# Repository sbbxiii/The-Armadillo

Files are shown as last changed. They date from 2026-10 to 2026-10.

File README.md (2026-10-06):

# 🛡️ The Armadillo: Custom ATmega328P + TMC2209 Stepper Motor Controller PCB








---

## 1. Executive Summary

**The Armadillo** is an open-source, Arduino-compatible motion control PCB designed from first principles in **KiCad 10.0.1**. It pairs the reliable **Microchip ATmega328P** 8-bit AVR microcontroller with the high-performance **Trinamic TMC2209-LA** silent bipolar stepper motor driver on a rugged $60.0\text{ mm} \times 60.0\text{ mm}$ 2-layer FR-4 board.

Featuring an onboard **WCH CH340K** USB-to-UART converter with automated DTR auto-reset, The Armadillo provides seamless plug-and-play programming directly through the Arduino IDE, PlatformIO, or AVR-GCC toolchains. Key features include silent stepper motion via **StealthChop2™**, sensorless homing via **StallGuard4™**, dynamic runtime current tuning over a single-wire **PD_UART** interface, and hardware RC-filtered sensor inputs.

---

## 2. 3D Raytraced Visualizations

<p align="center">
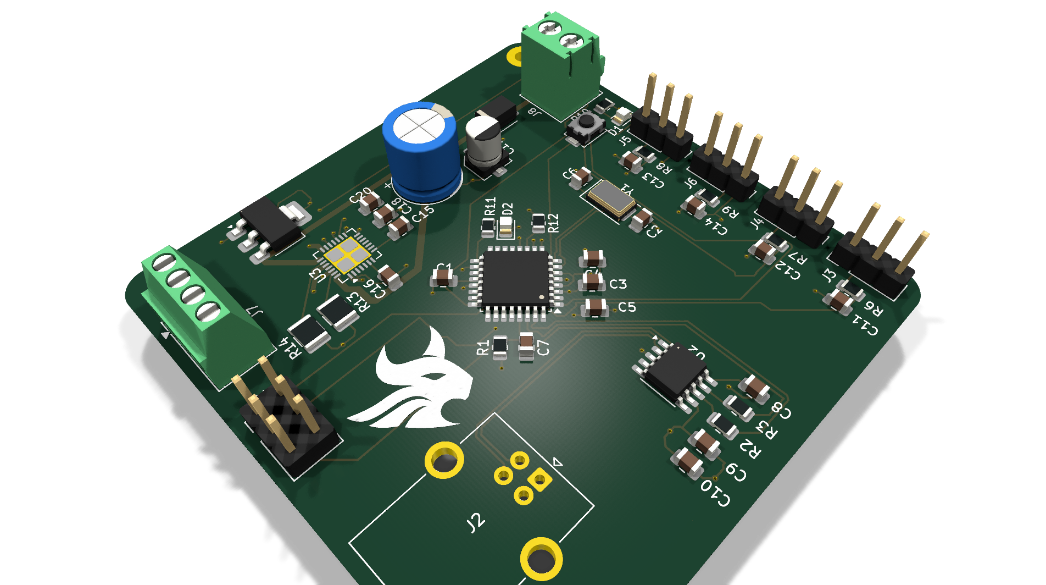
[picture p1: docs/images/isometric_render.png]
The Armadillo 3D Perspective Raytrace
  <br>
  <em>Figure 1: Raytraced 3D perspective view of The Armadillo motor controller board showing the ATmega328P core, TMC2209 driver, and screw terminal I/O.</em>
</p>

| Top View (Silicon, Connectors & SMT Layout) | Bottom View (Solid Ground Return & Driver Thermal Vias) |
| :---: | :---: |
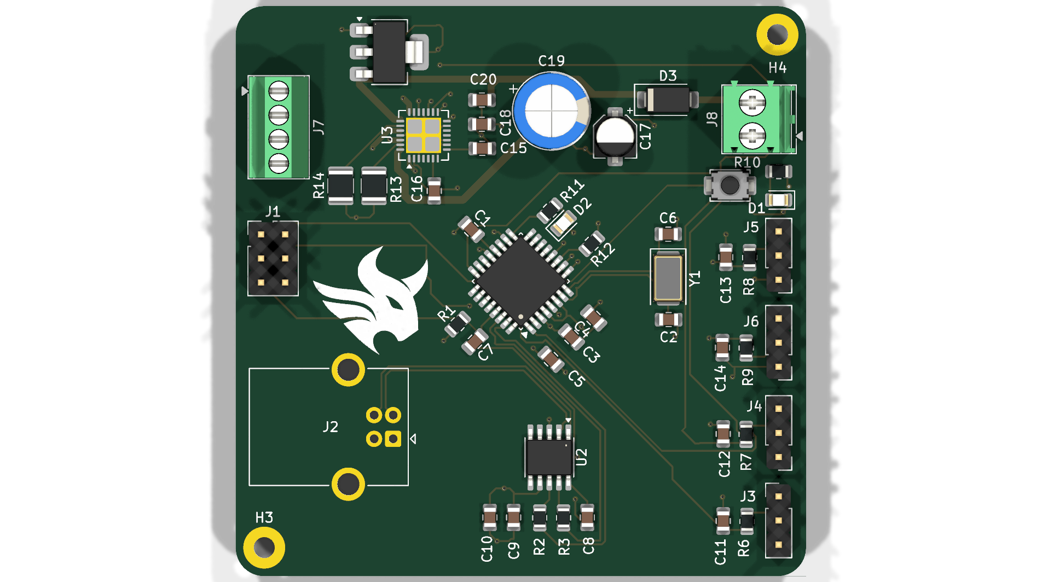
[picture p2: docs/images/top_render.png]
Top View
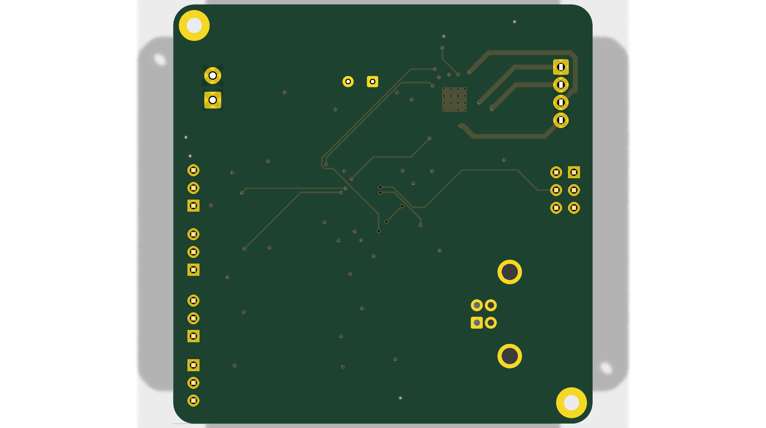
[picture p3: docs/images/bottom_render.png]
Bottom View
|  |  |

---

## 3. Circuit Architecture & Block Diagram

```mermaid
flowchart TD
    subgraph Power_Subsystem ["Power Distribution Network (PDN)"]
        VIN["Motor Power (4.75V - 29V)<br/>Terminal Block J8"] --> BulkCap["Bulk Decoupling<br/>100µF Radial + 2x 100nF"]
        BulkCap --> VMOT["VMOT Supply Rail"]
        VMOT --> LDO["NCP1117-5.0 LDO<br/>(Steps to +5V Logic)"]
        USB["USB Type-B Port (J2)"] --> Schottky["SS14 Schottky Diode (D3)"]
        Schottky --> VCC5["+5V System VCC Rail"]
        LDO --> VCC5
    end

    subgraph MCU_Subsystem ["Microcontroller & Communications"]
        VCC5 --> MCU["ATmega328P-A (TQFP-32)<br/>16.000 MHz Clock"]
        CH340["CH340K USB-UART (U2)"] <-->|"UART RX/TX + DTR Reset"| MCU
        ICSP["6-Pin AVR ISP Header (J1)"] <-->|"SPI MOSI/MISO/SCK/RST"| MCU
        MCU --> LEDS["Power & Diagnostic LEDs<br/>(D1, D2)"]
    end

    subgraph Motion_Subsystem ["Silent Motion Control"]
        VMOT --> TMC["Trinamic TMC2209-LA (U3)<br/>Silent Stepper Driver"]
        VCC5 --> TMC
        MCU -->|"M1_STEP / M1_DIR / EN"| TMC
        MCU <-->|"PD_UART (Single-Wire)"| TMC
        TMC --> SenseRes["Dual 0.11Ω 1210 Sense Resistors<br/>(R13, R14)"]
        TMC --> MotorOut["4-Phase Stepper Terminal (J7)<br/>(A1, A2, B1, B2)"]
    end

    subgraph IO_Subsystem ["Filtered Sensor Inputs"]
        Sensors["Endstops / Sensors (J3 - J6)"] --> RCFilt["RC Low-Pass Filters<br/>(1.5kΩ + 100nF)"]
        RCFilt --> MCU
    end
```

---

## 4. Hardware Specifications & Feature Matrix

### Electrical & Mechanical Metrics
| Specification | Parameter Value | Engineering Notes |
| :--- | :--- | :--- |
| **Board Footprint** | $60.00\text{ mm} \times 60.00\text{ mm}$ | Compact square profile with 3.0 mm radius rounded corners |
| **Mounting Pattern** | 4× M3 Mounting Holes | Positioned at corners for rigid enclosure mounting |
| **Layer Stackup** | 2-Layer FR-4 (1.6 mm thickness) | Top signal/routing + solid bottom GND return plane |
| **Motor Input Voltage ($V_S$)** | **4.75V to 29.0V DC** | Accepts standard 12V or 24V industrial/3D-printer power supplies |
| **Motor Peak Current** | **2.8A Peak / 2.0A RMS** | Configurable in software via TMC2209 internal registers |
| **Current Sense Resistors** | Dual $0.11\ \Omega \pm 1\%$ (1210 SMT) | High power dissipation footprint for thermal stability |
| **Microstepping Modes** | Up to **1/256** | Native 1/16 with MicroPlyer™ interpolation to 1/256 |
| **Microcontroller** | ATmega328P-A (TQFP-32) | 32 KB Flash, 2 KB SRAM, 1 KB EEPROM @ 16 MHz |
| **USB Interface** | CH340K (SSOP-10) | Built-in clock, requires no external crystal |
| **Design Rule Check (DRC)** | **0 Errors, 0 Unconnected Items** | 100% compliant with standard 2-layer PCB fabrication rules |

---

## 5. Trinamic TMC2209 Key Technologies

1. **StealthChop2™**: Voltage-regulated chopper providing completely silent motor movement at low and medium velocities. Eliminates motor whine.
2. **SpreadCycle™**: Highly dynamic current control chopper mode that delivers high torque and precise microstepping at high step frequencies.
3. **StallGuard4™**: Real-time sensorless load measurement that detects mechanical endstops by monitoring motor back-EMF, eliminating mechanical limit switches.
4. **Single-Wire PD_UART**: Allows the ATmega328P to dynamically tune drive current, chopper thresholds, microstep resolution, and read motor diagnostics via one GPIO pin.

---

## 6. Pinout & Peripheral Mapping

### Microcontroller Pin Mapping
| ATmega328P Pin | Net Name | Hardware Function / Target Peripheral |
| :---: | :--- | :--- |
| **Pin 1 (PD3)** | `M1_STEP` | Step pulse command to TMC2209 Pin 16 |
| **Pin 2 (PD4)** | `M1_DIR` | Direction pulse command to TMC2209 Pin 17 |
| **Pin 9 (PB6)** | `XTAL1` | 16.000 MHz Crystal Oscillator ($Y1$) |
| **Pin 10 (PB7)** | `XTAL2` | 16.000 MHz Crystal Oscillator ($Y1$) |
| **Pin 11 (PD5)** | `EN` | Motor output enable/disable (active low) to TMC2209 Pin 18 |
| **Pin 12 (PD6)** | `PD_UART` | Half-duplex single-wire UART communication with TMC2209 Pin 20 |
| **Pin 13 (PD7)** | `DIAGNOSTIC` | StallGuard / fault flag input from TMC2209 Pin 22 |
| **Pin 15 (PB1)** | `DIGITAL_IN1` | Filtered digital input via header $J5$ (RC filtered) |
| **Pin 16 (PB2)** | `DIGITAL_IN2` | Filtered digital input via header $J6$ (RC filtered) |
| **Pin 17 (PB3)** | `MOSI` | SPI Master Out / In-System Programming ($J1$) |
| **Pin 18 (PB4)** | `MISO` | SPI Master In / In-System Programming ($J1$) |
| **Pin 19 (PB5)** | `SCK` | SPI Clock / In-System Programming ($J1$) |
| **Pin 23 (PC0)** | `ANALOG_IN3` | Filtered analog/digital input via header $J3$ |
| **Pin 24 (PC1)** | `ANALOG_IN4` | Filtered analog/digital input via header $J4$ |
| **Pin 29 (PC6)** | `RESET` | Active-low reset tied to tactile switch $SW1$ and CH340K DTR line |
| **Pin 30 (PD0)** | `RXD` (`UART-`) | Hardware UART receive from CH340K USB bridge |
| **Pin 31 (PD1)** | `TXD` (`UART+`) | Hardware UART transmit to CH340K USB bridge |

### External Connectors
| Connector | Type | Net Connections | Function |
| :--- | :--- | :--- | :--- |
| **J1** | 2×3 2.54mm Header | MOSI, MISO, SCK, RESET, VCC, GND | Standard AVR ICSP programming port |
| **J2** | USB Type-B Female | VBUS, D-, D+, GND | PC programming and USB serial communication |
| **J3** | 1×3 2.54mm Header | VCC, `ANALOG_IN3` (filtered), GND | Sensor / Potentiometer input |
| **J4** | 1×3 2.54mm Header | VCC, `ANALOG_IN4` (filtered), GND | Sensor / Limit switch input |
| **J5** | 1×3 2.54mm Header | VCC, `DIGITAL_IN1` (filtered), GND | Optical / Mechanical Endstop input |
| **J6** | 1×3 2.54mm Header | VCC, `DIGITAL_IN2` (filtered), GND | Optical / Mechanical Endstop input |
| **J7** | 4-Pin 2.54mm Screw Terminal | Motor Coils: `A1`, `A2`, `B1`, `B2` | Stepper motor phase output |
| **J8** | 2-Pin 3.5mm Screw Terminal | `VIN` ($4.75\text{V} - 29\text{V}$), `GND` | Main motor power supply input |

---

## 7. Deliverables & Production Assets

| Asset Category | File Path | Description |
| :--- | :--- | :--- |
| **Schematic Vector PDF** | [`schematic/ATmega_TMC2209_Schematic.pdf`](schematic/ATmega_TMC2209_Schematic.pdf) | High-resolution printable schematic |
| **Schematic Vector SVG** | [`schematic/ATmega_TMC2209_Schematic.svg`](schematic/ATmega_TMC2209_Schematic.svg) | Scalable vector graphic of complete circuit |
| **Bill of Materials** | [`manufacturing/ATmega_TMC2209_BOM.csv`](manufacturing/ATmega_TMC2209_BOM.csv) | Full component list with footprints and quantities |
| **Fabrication Package** | [`manufacturing/ATmega_TMC2209_Gerbers_Rev1.zip`](manufacturing/ATmega_TMC2209_Gerbers_Rev1.zip) | Production gerbers & Excellon drill file |
| **KiCad 10 Project** | [`hardware/`](hardware/) | Native `.kicad_pro`, `.kicad_sch`, and `.kicad_pcb` CAD files |

---

## 8. Author & License

* **Designed & Engineered by:** Osakwe Nmesoma Chukwukadibia ([@sbbxiii](https://github.com/sbbxiii))
* **License:** [MIT License](LICENSE)

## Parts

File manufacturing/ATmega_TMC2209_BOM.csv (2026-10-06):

Refs | Value | Footprint | Qty | DNP
C1 | 100nF | Capacitor_SMD:C_0805_2012Metric | 1
C2 | 22pF | Capacitor_SMD:C_0805_2012Metric | 1
C3 | 100nF | Capacitor_SMD:C_0805_2012Metric | 1
C4 | 100nF | Capacitor_SMD:C_0805_2012Metric | 1
C5 | 100nF | Capacitor_SMD:C_0805_2012Metric | 1
C6 | 22pF | Capacitor_SMD:C_0805_2012Metric | 1
C7 | 100nF | Capacitor_SMD:C_0805_2012Metric | 1
C8 | 100nF | Capacitor_SMD:C_0805_2012Metric | 1
C9 | 100nF | Capacitor_SMD:C_0805_2012Metric | 1
C10 | 100nF | Capacitor_SMD:C_0805_2012Metric | 1
C11 | 100nF | Capacitor_SMD:C_0805_2012Metric | 1
C12 | 100nF | Capacitor_SMD:C_0805_2012Metric | 1
C13 | 100nF | Capacitor_SMD:C_0805_2012Metric | 1
C14 | 100nF | Capacitor_SMD:C_0805_2012Metric | 1
C15 | 100nF | Capacitor_SMD:C_0805_2012Metric | 1
C16 | 100nF | Capacitor_SMD:C_0805_2012Metric | 1
C17 | 4.7uF | Capacitor_SMD:CP_Elec_4x5.3 | 1
C18 | 100nF | Capacitor_SMD:C_0805_2012Metric | 1
C19 | 100uF | Capacitor_THT:CP_Radial_D8.0mm_P3.50mm | 1
C20 | 100nF | Capacitor_SMD:C_0805_2012Metric | 1
D1 | POWER_LED | LED_SMD:LED_0805_2012Metric | 1
D2 | DIAGNOSTIC | LED_SMD:LED_0805_2012Metric | 1
D3 | SS14 | Diode_SMD:D_SMA | 1
J1 | ISP | Connector_PinHeader_2.54mm:PinHeader_2x03_P2.54mm_Vertical | 1
J2 | USB_B | Connector_USB:USB_B_OST_USB-B1HSxx_Horizontal | 1
J3 | J_IN3 | Connector_PinHeader_2.54mm:PinHeader_1x03_P2.54mm_Vertical | 1
J4 | J_IN4 | Connector_PinHeader_2.54mm:PinHeader_1x03_P2.54mm_Vertical | 1
J5 | J_IN1 | Connector_PinHeader_2.54mm:PinHeader_1x03_P2.54mm_Vertical | 1
J6 | J_IN2 | Connector_PinHeader_2.54mm:PinHeader_1x03_P2.54mm_Vertical | 1
J7 | Output_Phases | TerminalBlock_Phoenix:TerminalBlock_Phoenix_MPT-0,5-4-2.54_1x04_P2.54mm_Horizontal | 1
J8 | Power_Input | TerminalBlock_Phoenix:TerminalBlock_Phoenix_PT-1,5-2-3.5-H_1x02_P3.50mm_Horizontal | 1
R1 | 10kΩ | Resistor_SMD:R_0805_2012Metric | 1
R2 | 1kΩ | Resistor_SMD:R_0805_2012Metric | 1
R3 | 1kΩ | Resistor_SMD:R_0805_2012Metric | 1
R6 | R_FILTER 1.5kΩ | Resistor_SMD:R_0805_2012Metric | 1
R7 | R_FILTER 1.5kΩ | Resistor_SMD:R_0805_2012Metric | 1
R8 | R_FILTER 1.5kΩ | Resistor_SMD:R_0805_2012Metric | 1
R9 | R_FILTER 1.5kΩ | Resistor_SMD:R_0805_2012Metric | 1
R10 | 1kΩ | Resistor_SMD:R_0805_2012Metric | 1
R11 | 1kΩ | Resistor_SMD:R_0805_2012Metric | 1
R12 | 1kΩ | Resistor_SMD:R_0805_2012Metric | 1
R13 | 0.11Ω | Resistor_SMD:R_1210_3225Metric | 1
R14 | 0.11Ω | Resistor_SMD:R_1210_3225Metric | 1
SW1 | Reset_Button | Button_Switch_SMD:SW_SPST_TS-1088-xR020 | 1
U1 | ATmega328P-A | Package_QFP:TQFP-32_7x7mm_P0.8mm | 1
U2 | CH340K | Package_SO:SSOP-10-1EP_3.9x4.9mm_P1mm_EP2.1x3.3mm | 1
U3 | TMC2209-LA | Package_DFN_QFN:VQFN-28-1EP_5x5mm_P0.5mm_EP3.7x3.7mm_ThermalVias | 1
U4 | NCP1117-5.0_SOT223 | Package_TO_SOT_SMD:SOT-223-3_TabPin2 | 1
Y1 | 16MHz | Crystal:Crystal_SMD_5032-2Pin_5.0x3.2mm | 1

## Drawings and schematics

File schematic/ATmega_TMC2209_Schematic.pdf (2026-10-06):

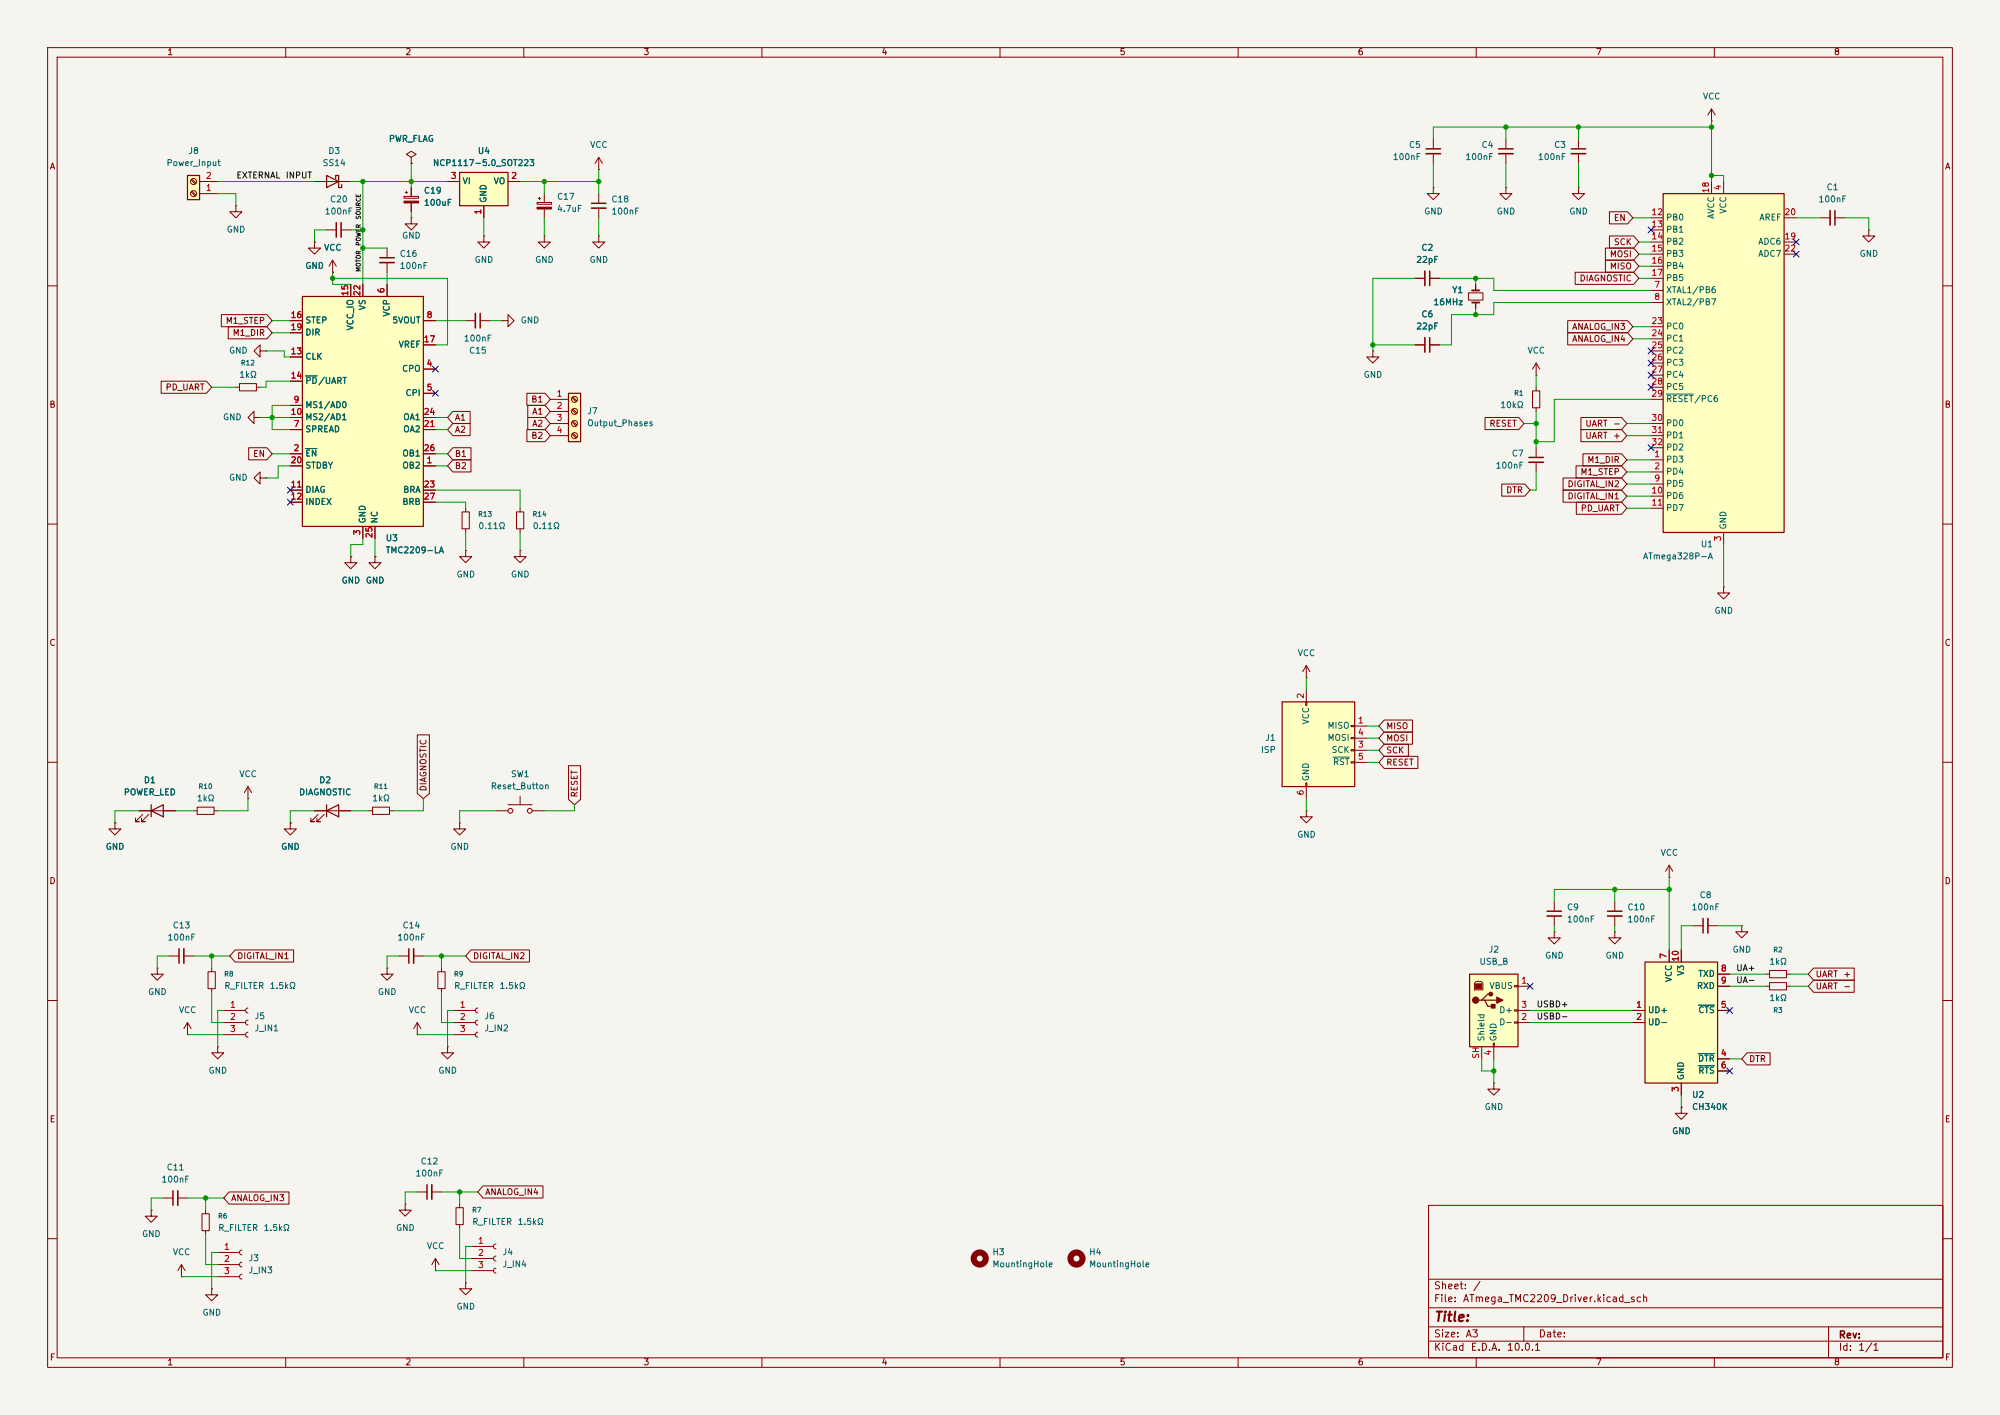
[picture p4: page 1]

ANALOG_IN4 MOTOR POWER SOURCE EXTERNAL INPUT

Size: A3 | Rev:
KiCad E.D.A. 10.0.1 | Id: 1/1

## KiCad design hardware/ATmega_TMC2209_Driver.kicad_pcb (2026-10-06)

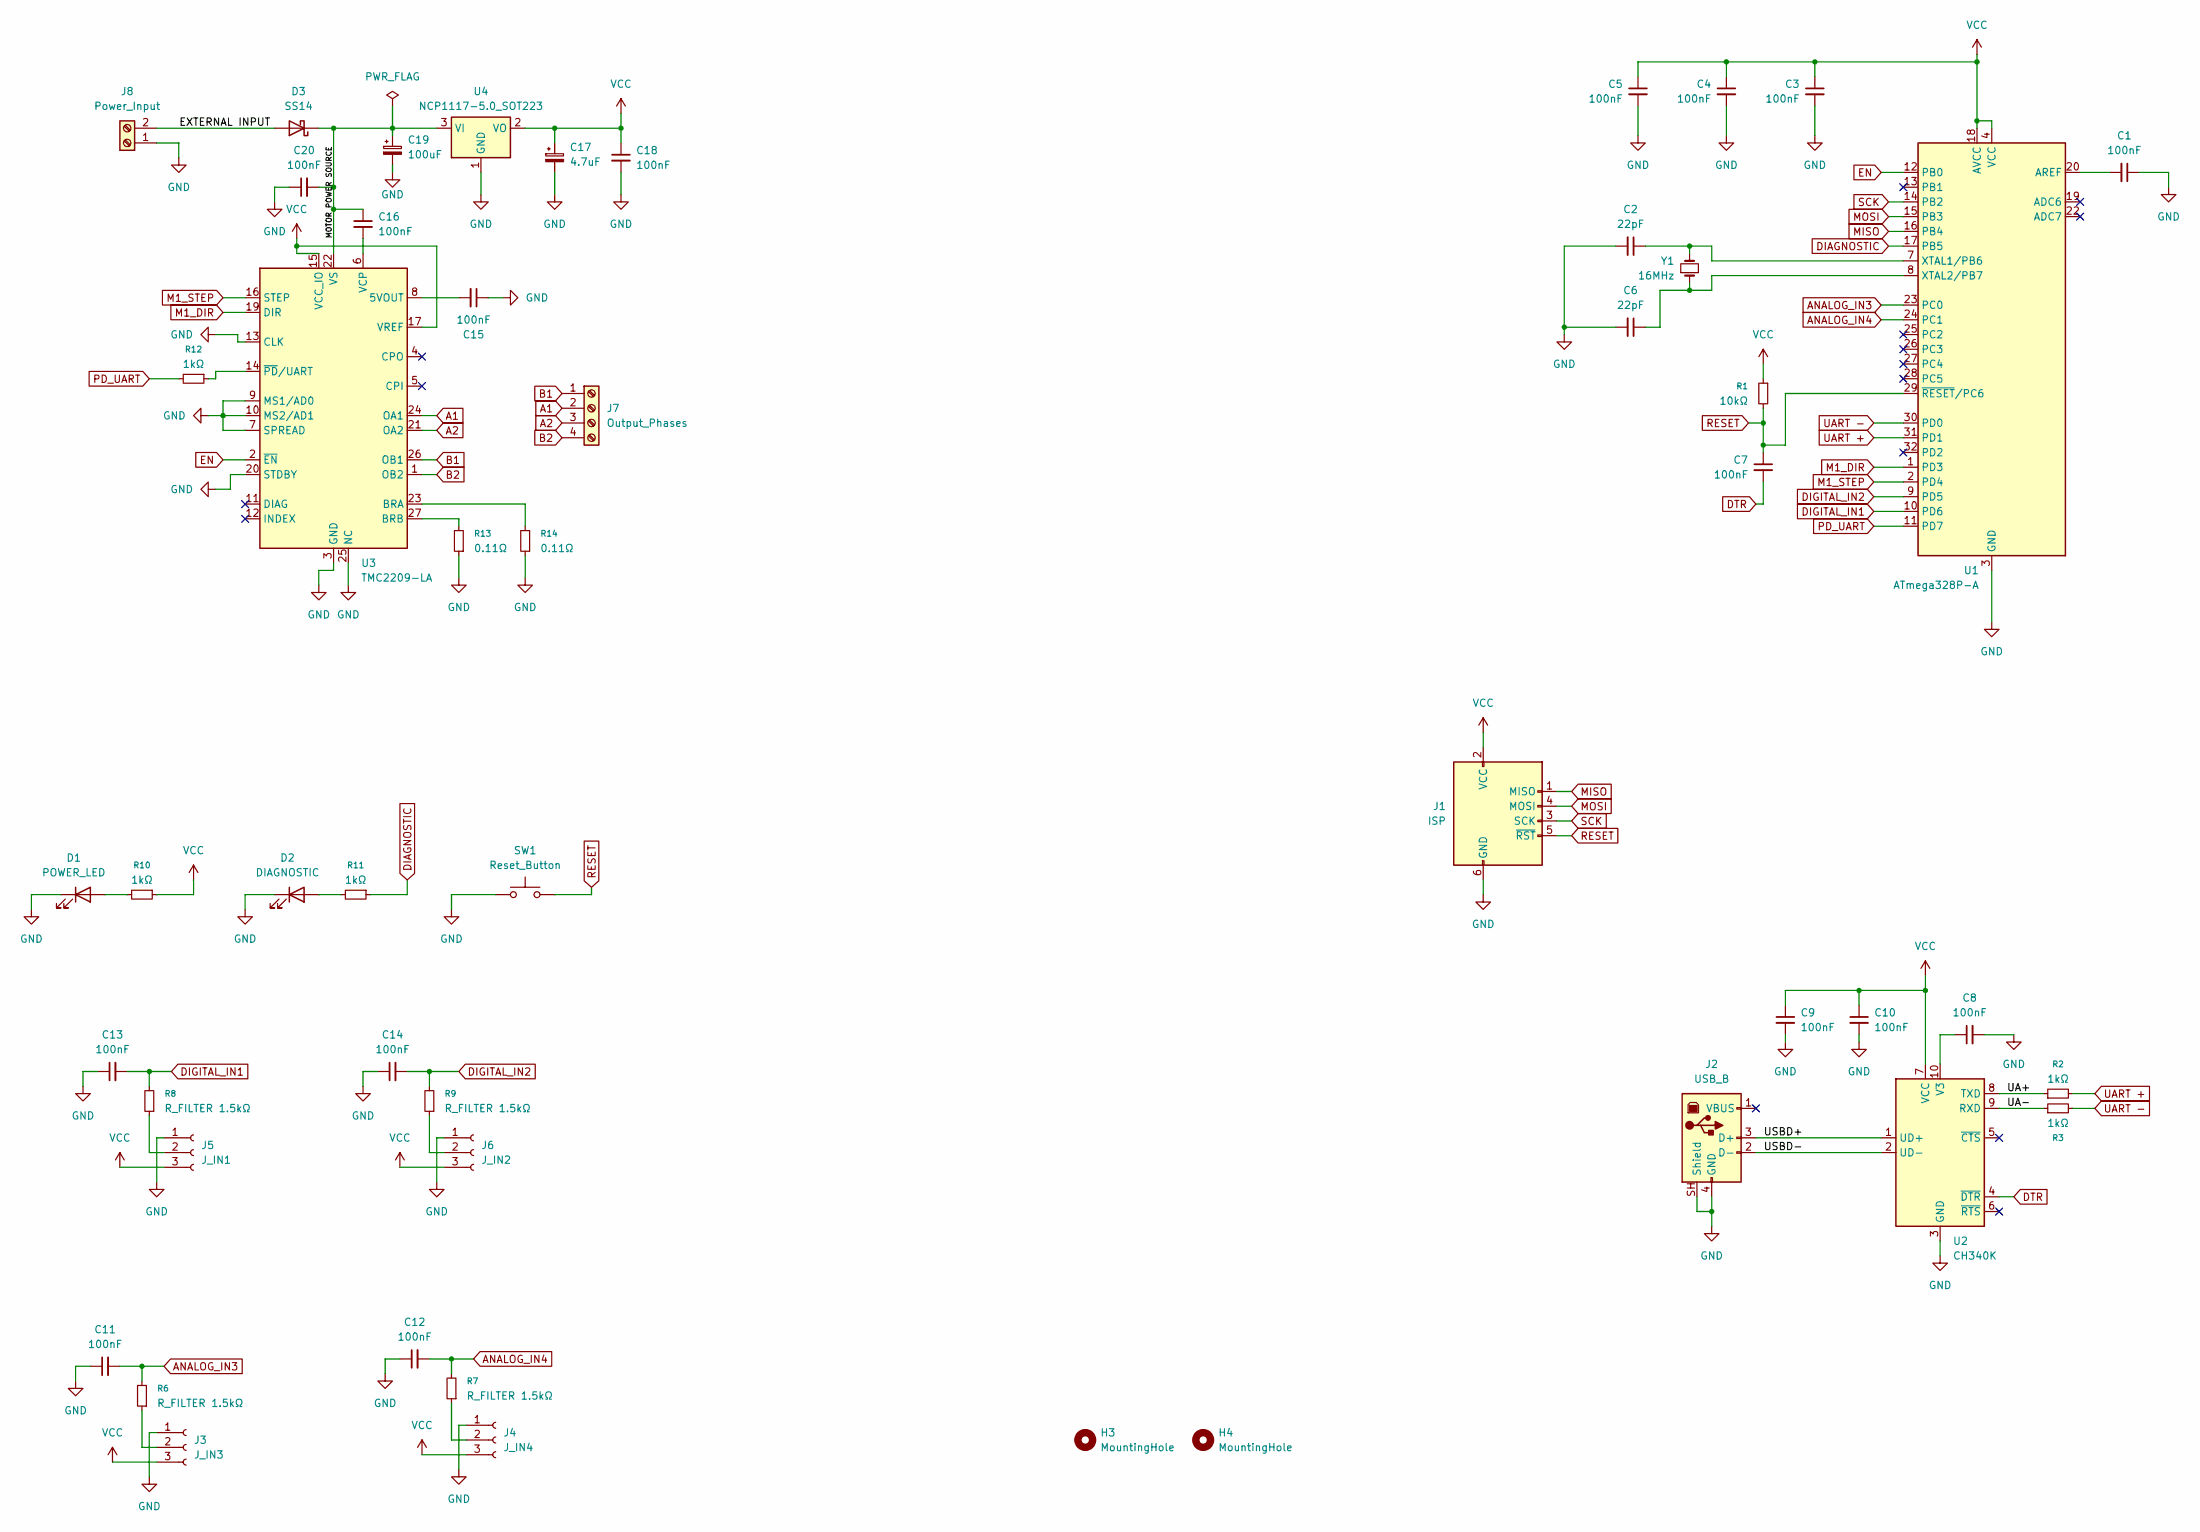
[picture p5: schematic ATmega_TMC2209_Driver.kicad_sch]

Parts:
C1, C3, C4, C5, C7, C8, C9, C10, C11, C12, C13, C14, C15, C16, C18, C20: 100nF; C_0805_2012Metric
C2, C6: 22pF; C_0805_2012Metric
C17: 4.7uF; CP_Elec_4x5.3
C19: 100uF; CP_Radial_D8.0mm_P3.50mm
D1: POWER_LED; LED_0805_2012Metric
D2: DIAGNOSTIC; LED_0805_2012Metric
D3: SS14; D_SMA
H3, H4: MountingHole; MountingHole_2.2mm_M2_Pad
J1: ISP; PinHeader_2x03_P2.54mm_Vertical
J2: USB_B; USB_B_OST_USB-B1HSxx_Horizontal
J3: J_IN3; PinHeader_1x03_P2.54mm_Vertical
J4: J_IN4; PinHeader_1x03_P2.54mm_Vertical
J5: J_IN1; PinHeader_1x03_P2.54mm_Vertical
J6: J_IN2; PinHeader_1x03_P2.54mm_Vertical
J7: Output_Phases; TerminalBlock_Phoenix_MPT-0,5-4-2.54_1x04_P2.54mm_Horizontal
J8: Power_Input; TerminalBlock_Phoenix_PT-1,5-2-3.5-H_1x02_P3.50mm_Horizontal
R1: 10kΩ; R_0805_2012Metric
R2, R3, R10, R11, R12: 1kΩ; R_0805_2012Metric
R6, R7, R8, R9: R_FILTER 1.5kΩ; R_0805_2012Metric
R13, R14: 0.11Ω; R_1210_3225Metric
SW1: Reset_Button; SW_SPST_TS-1088-xR020
U1: ATmega328P-A; TQFP-32_7x7mm_P0.8mm
U2: CH340K; SSOP-10-1EP_3.9x4.9mm_P1mm_EP2.1x3.3mm
U3: TMC2209-LA; VQFN-28-1EP_5x5mm_P0.5mm_EP3.7x3.7mm_ThermalVias
U4: NCP1117-5.0_SOT223; SOT-223-3_TabPin2
Y1: 16MHz; Crystal_SMD_5032-2Pin_5.0x3.2mm

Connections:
/EXTERNAL INPUT: D3.2 (A), J8.2
/MOTOR POWER SOURCE: C16.1, C19.1, C20.2, D3.1 (K), U3.22 (VS), U3.28 (VS), U4.3 (VI)
/UA+: R2.1, U2.8 (TXD)
/UA-: R3.1, U2.9 (RXD)
/USBD+: J2.3 (D+), U2.1 (UD+)
/USBD-: J2.2 (D-), U2.2 (UD-)
A1: J7.2, U3.24 (OA1)
A2: J7.3, U3.21 (OA2)
ANALOG_IN3: C11.2, R6.2, U1.23 (PC0)
ANALOG_IN4: C12.2, R7.2, U1.24 (PC1)
B1: J7.1, U3.26 (OB1)
B2: J7.4, U3.1 (OB2)
DIAGNOSTIC: R11.1, U1.17 (PB5)
DIGITAL_IN1: C13.2, R8.2, U1.10 (PD6)
DIGITAL_IN2: C14.2, R9.2, U1.9 (PD5)
DTR: C7.2, U2.4 (~DTR)
EN: U1.12 (PB0), U3.2 (~EN)
GND: C1.1, C2.2, C3.2, C4.2, C5.2, C6.2, C8.2, C9.2, C10.2, C11.1, C12.1, C13.1, C14.1, C15.1, C17.2, C18.2, C19.2, C20.1, D1.1 (K), D2.1 (K), J1.6 (GND), J2.4 (GND), J2.SH (Shield), J3.1, J4.1, J5.1, J6.1, J8.1, R13.1, R14.1, SW1.1, U1.3 (GND), U1.5 (GND), U1.21 (GND), U2.3 (GND), U2.11 (GND), U3.3 (GND), U3.7 (SPREAD), U3.9 (MS1/AD0), U3.10 (MS2/AD1), U3.13 (CLK), U3.18 (GND), U3.20 (STDBY), U3.25 (NC), U3.29 (GND), U4.1 (GND)
M1_DIR: U1.1 (PD3), U3.19 (DIR)
M1_STEP: U1.2 (PD4), U3.16 (STEP)
MISO: J1.1 (MISO), U1.16 (PB4)
MOSI: J1.4 (MOSI), U1.15 (PB3)
unnamed: D1.2 (A), R10.2
unnamed: D2.2 (A), R11.2
unnamed: J3.2, R6.1
unnamed: J4.2, R7.1
unnamed: J5.2, R8.1
unnamed: J6.2, R9.1
unnamed: C1.2, U1.20 (AREF)
unnamed: C2.1, U1.7 (XTAL1/PB6), Y1.2
unnamed: C6.1, U1.8 (XTAL2/PB7), Y1.1
unnamed: C8.1, U2.10 (V3)
unnamed: C15.2, U3.8 (5VOUT)
unnamed: R14.2, U3.23 (BRA)
unnamed: R13.2, U3.27 (BRB)
unnamed: C16.2, U3.6 (VCP)
unnamed: R12.1, U3.14 (~PD/UART)
PD_UART: R12.2, U1.11 (PD7)
RESET: C7.1, J1.5 (~RST), R1.2, SW1.2, U1.29 (~RESET/PC6)
SCK: J1.3 (SCK), U1.14 (PB2)
UART +: R2.2, U1.31 (PD1)
UART -: R3.2, U1.30 (PD0)
VCC: C3.1, C4.1, C5.1, C9.1, C10.1, C17.1, C18.1, J1.2 (VCC), J3.3, J4.3, J5.3, J6.3, R1.1, R10.1, U1.4 (VCC), U1.6 (VCC), U1.18 (AVCC), U2.7 (VCC), U3.15 (VCC_IO), U3.17 (VREF), U4.2 (VO)

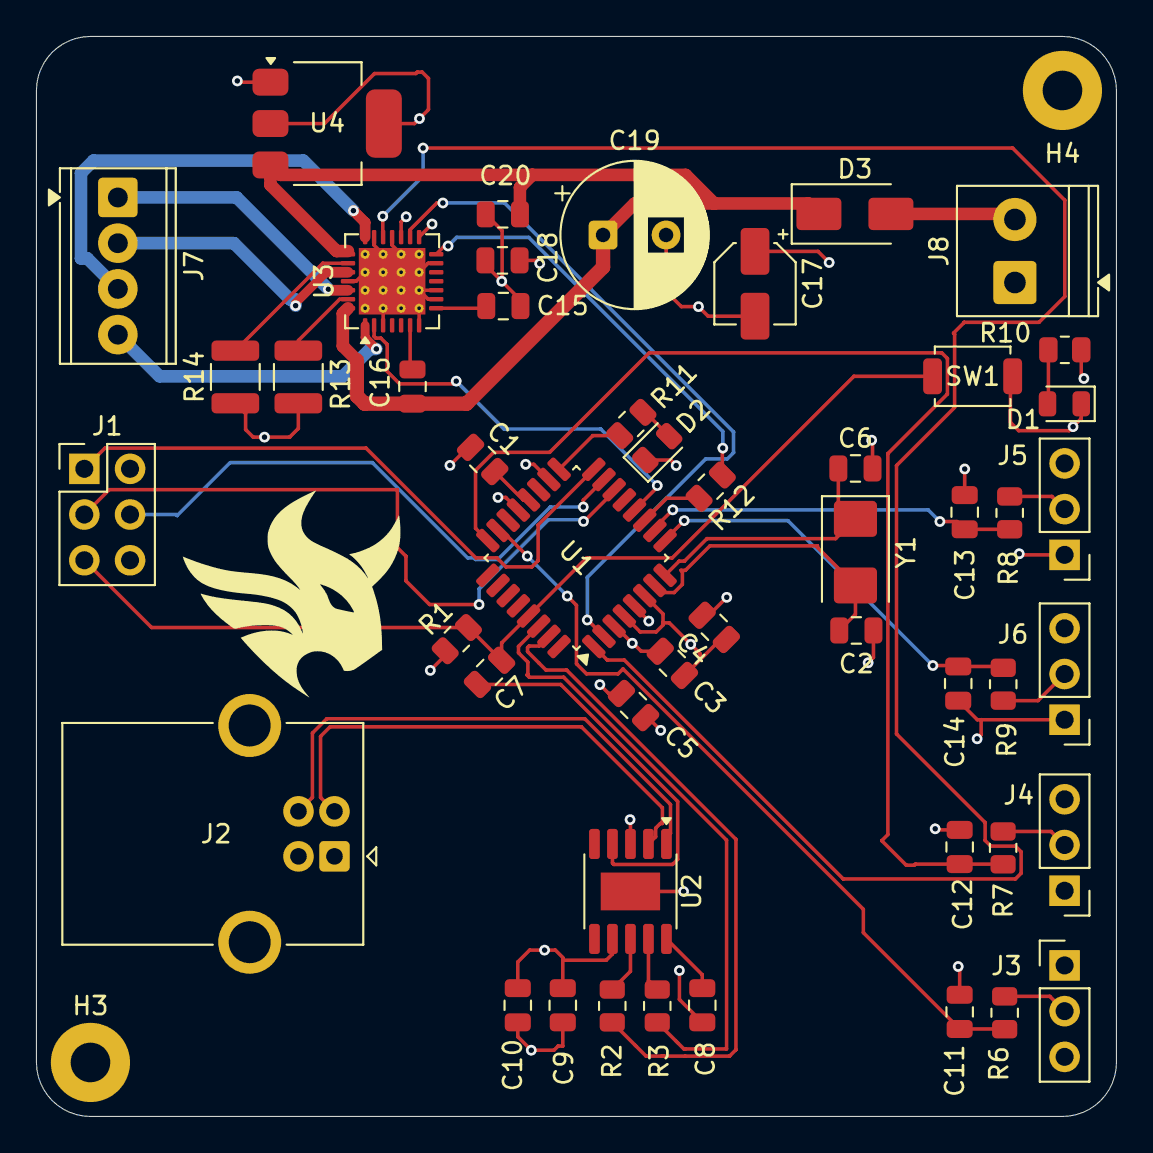
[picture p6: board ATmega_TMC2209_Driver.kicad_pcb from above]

Board: 4 copper layers, 60.0 x 60.0 mm, 51 parts (0 on the bottom side), 43 nets.
